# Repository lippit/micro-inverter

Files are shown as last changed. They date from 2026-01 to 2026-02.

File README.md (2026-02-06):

# An open-source - community built micro-inverter

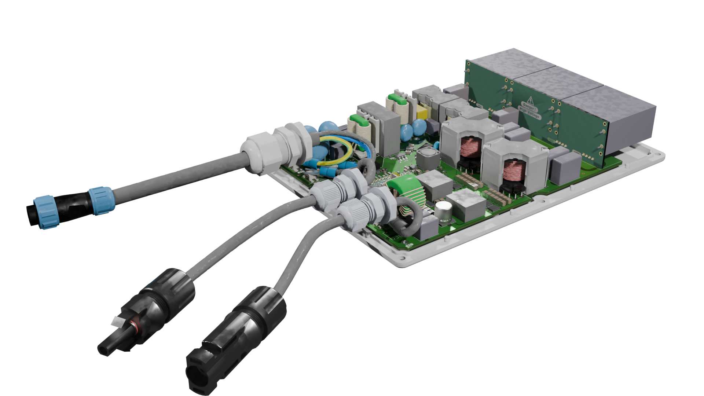
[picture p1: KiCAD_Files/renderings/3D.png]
3D view


## Manifesto 

The project goal are : 

- Having the first open source PV micro-inverter
- Finally a design easy to repair that is no longer a black box
- Redeem your data sovereignty, you will no longer depend on a proprietary cloud to follow your solar production and consumption. 

## Open, for everyone, forever

- This project is propulsed by its community. 
- The collective work generated is meant to remain open. 
- Design files are made with open source software - Namely kiCAD.
- Mechanical interfaces and components are modeled using FreeCAD.
- Simulation files use ngSpice.

In that sense, the owntech foundation aims at protecting this technical common.

## Specifications
This section is inspired from OpenMi

Comparison of micro-inverters with rated output power between 350VA and 400VA:

| Model | HM-350 | HM-400 | IQ7A |EVT300  |TSOL-M800  |
|:---|:---:|:---:|:---:|:---:|:---:|
| Manufacturer | Hoymiles | Hoymiles | Enphase | Envertech | TSUN |
| Number of solar panels | 1 | 1 | 1 | 1 | 2 |
| Recommended input power (W) | 280-470+ | 320-540+ | 295-460 | 180-420+ |2 $\cdot$ 280-440|
| $V_{MPPT,min}$ (V) | 33 | 34 | 38 (18) | 24 | 33 |
| $V_{MPPT,max}$ (V) | 48 | 48 | 43 (58) | 45 | 48 |
| Start-up voltage (V) | 22 | 22 | 22 | - | - |
| Operating volage range (V) | 16-60 | 16-60 | 16-58 | 18-54 | 16-60 |
| Maximum input current (A) | 11.5 | 12 | 12 | 12 | 11.5 |
| Maximum input short circuit current (A)| 15 | 15 | 20 | 15 | 15 |
| Rated output power (VA) | 350 | 400 | 349 | 300 | 600 |
| Peak efficiency (%) | 96.7 | 96.7 | 97.7 | 95.4 | 96.7 |
| CEC weighted efficiency (%) | 96.5 | 96.5 | 97.0 | 95.0 | 96.5 |

### uVerter Target specifications

| Category | Requirement | Notes |
|---|---:|---|
| Grid | 220 V AC to 250V AC / 50 to 60 Hz | Hardware not compatible with 110V grids |
| Grid compliance | Grid-code compliant | Exact certification scope depends on country / standard |
| Rated apparent power | 450 VA | Software-limited power cap supported |
| Input DC operating range | 16 V – 58 V | PV module operating window |
| Recommended PV input power | 350 W – 550 W | Depends on module and thermal conditions |
| Efficiency | > 95% | Target at nominal conditions |
| Power factor | ≈ 1 | Near-unity PF at rated power |
| THD | < 5% | Total harmonic distortion at rated conditions |
| Isolation | Galvanic isolation | Electrical isolation between PV and grid |
| Operating temperature | -40 °C to +60 °C | Derating may apply |
| Repairability | No invasive potting | Designed to be serviceable / inspectable |
| Connectivity | Wi-Fi | Local-first monitoring (no proprietary cloud required) |

## Renderings

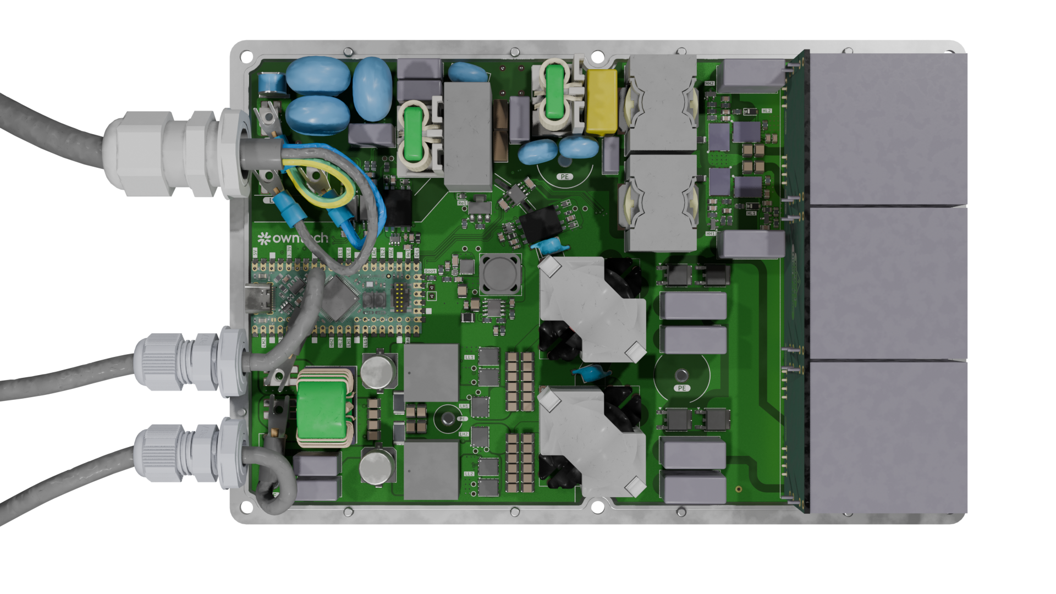
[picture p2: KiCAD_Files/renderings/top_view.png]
Top view


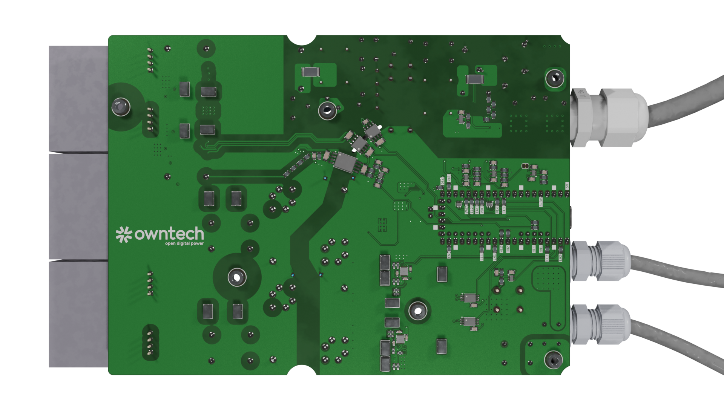
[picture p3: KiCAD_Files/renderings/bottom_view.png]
Bottom view


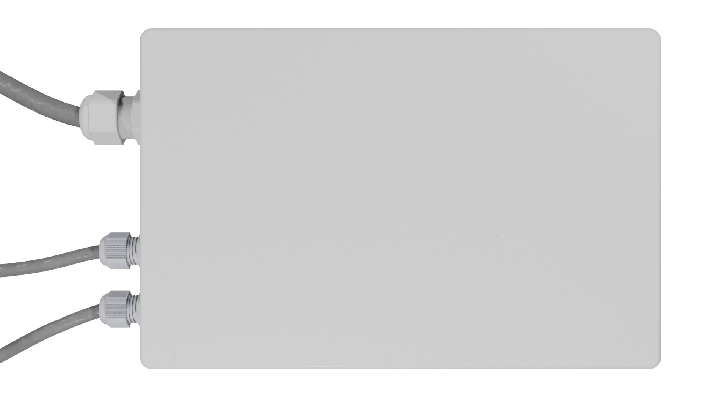
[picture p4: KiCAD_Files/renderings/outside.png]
Outside view


## Control overview

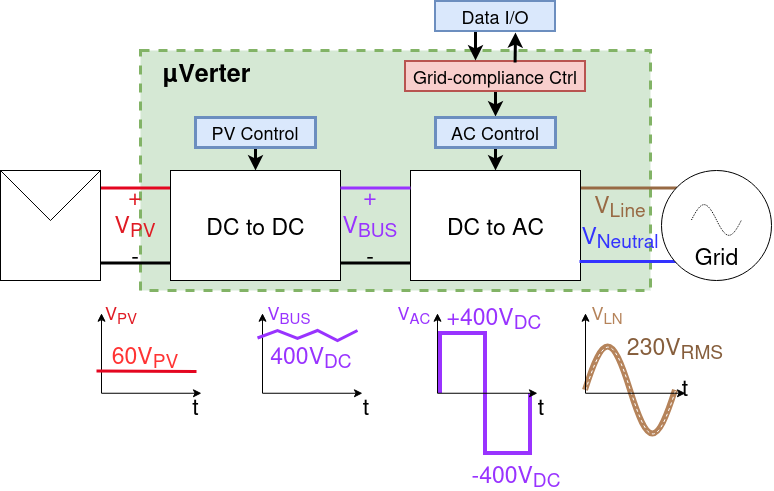
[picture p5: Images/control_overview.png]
Control overview


The control overview shows the uVerter as two coordinated stages: a PV-controlled DC/DC front end that regulates the panel operating point and raises the DC bus, followed by an AC control stage that shapes a grid-compliant AC output. Measurements and commands flow through Data I/O and the grid-compliance controller so the inverter can synchronize to line/neutral, limit harmonics, and maintain safe operation while power flows from the PV input to the grid.

## Firmware overview

The `firmware/src/main.cpp` file is the entry point for the uVerter firmware: it configures the sensors and power stages, sets up the real-time and background tasks, and runs the state machine plus control loops that drive the boost and inverter legs based on measurements and synchronization status.

- Real-time control runs in `loop_critical_task()` at 100 µs to read sensors, enforce protections, regulate the boost stage, compute duty cycles, and update grid-sync variables.
- Supervisory logic runs in `loop_application_task()` to manage modes (idle/startup/power/error), handle transitions, and expose telemetry through the user data API.

### Compiling

Micro-inverter uses [PlatformIO](https://platformio.org/) as it's build and dependency management system.

#### From the command line

1. Create and activate a Python virtual environment.

        python3 -m venv .owntech-venv
        source .owntech-venv/bin/activate

2. Install PlatformIO.

        pip3 install platformio

3. Compile the code. Dependencies (including Zephyr and Owntech libraries) are downloaded automatically.

        cd micro-inverter/firmware/
        pio run

#### In Visual Studio Code

1. Install the "PlatformIO IDE" extension
2. Open the `firmware` directory via PlatformIO's home screen (**not** with VSCode's File -> Open)
3. Press the "Build" button in the PlatformIO toolbar (found on the bottom left)

## Contribute 

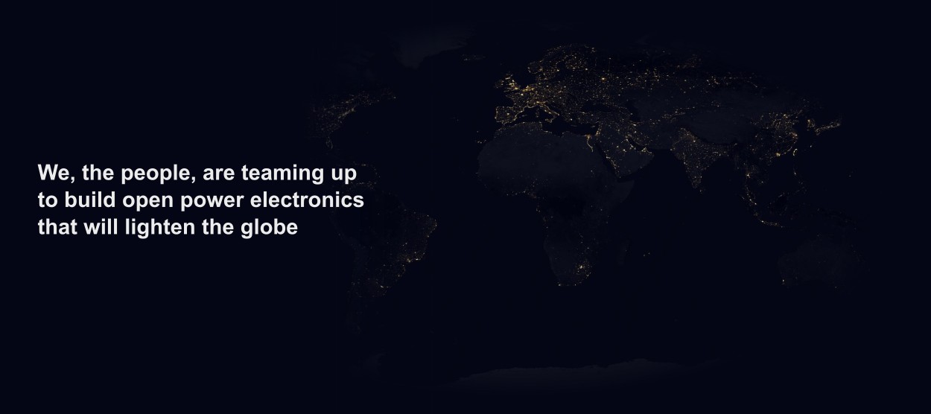
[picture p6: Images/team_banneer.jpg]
Team banneer


### Spread the word

- ⭐ Star this repository  

- Share the project with PV / power electronics / open-hardware communities  

- Mention it in meetups, forums, maker spaces, or your local energy co-op  

### Give feedback and report issues

Help us improve by opening GitHub issues:

- Bug reports (schematic/PCB mistakes, BOM mismatches, mechanical interferences)  

- Documentation gaps (unclear steps, missing diagrams, confusing naming)  

- Feature requests  

### Choose a contribution path

Start with Contribute.md — a living list of work items the community can pick up.  
Whether you’re a student looking for a thesis topic, an engineer wanting to review a safety-critical design, or a maker growing skills in hardware and firmware: you’re welcome here.  

Bring what you have: time, curiosity, test equipment, careful eyes, lived experience installing or repairing PV gear.  
Let’s build an inverter that isn’t a black box — and keep it open, for everyone, forever.  

## Safety first  

### Disclaimer
This project is shared as-is, without any warranty of any kind, and without any guarantee of compliance with safety, EMC, or grid-connection regulations.
By building, modifying, or using this design, you accept full responsibility for verification, testing, certification (if applicable), and safe operation.

Do not connect a prototype to the public grid.
Grid connection must only happen after appropriate validation, protections, and (where required) third-party certification.

### Mind the risks  
Building a micro-inverter is an advanced DIY project. It combines high energy, high voltage, fast switching, and grid interaction — a mix that can injure, start fires, or damage property

Key hazards include:

- Electric shock and electrocution
Internal stages can reach hundreds of volts. Multiple nets are high voltage. Some capacitors can stay charged after power-off. Treat the system as live until proven discharged and measured.

- Fire and thermal runaway
Faults can turn traces, connectors, inductors, or semiconductors into heaters in seconds. Thermal issues can escalate quickly.

### A community note
We want this project to be open — not reckless. If you spot a safety issue (creepage/clearance, insulation, thermal margins, protection logic, connector ratings, etc.), please report it.
Safety improvements are contributions that protect everyone.

## Standards and directives

### Relevant EU directives for CE

- Directive 2001/95/EC: General Product Safety
- Directive 2014/30/EU: Electromagnetic Compatibility (EMC)
- Directive 2014/35/EU: Low Voltage (LVD)
- Directive 2014/53/EU: Radio Equipment (RED)
- Directive 2011/65/EU: Restriction of the use of certain Hazardous Substances (RoHS)

### Low Voltage Directive (LVD)

**EN IEC 62109-1:2010**
Safety of power converters for use in photovoltaic power systems - Part 1: General requirements

**EN IEC 62109-2:2011**
Safety of power converters for use in photovoltaic power systems - Part 2: Particular requirements for inverters

### Electromagnetic Compatibility (EMC)

**EN 62920:2017+A11+A1:2021**
Photovoltaic power generating systems - EMC requirements and test methods for power conversion equipment

**ETSI EN 301 489-1**
ElectroMagnetic Compatibility (EMC) standard for radio equipment and services; Part 1: Common technical requirements

**ETSI EN 301 489-17**
ElectroMagnetic Compatibility (EMC) standard for radio equipment and services; Part 17: Specific conditions for Broadband Data Transmission Systems

### Radio Equipment Directive (RED)

**ETSI EN 300 328 V2.2.2**
Wideband transmission systems; Data transmission equipment operating in the 2,4 GHz band; Harmonised Standard for access to radio spectrum

### Grid Regulations

As grid regulations are country specific, please refer to Grid regulations

## Licence 

This project is licenced under **CERN-OHL-V2-S** open source hardware licence. Licence file can be found under `License/cern-ohl-v2-s`.

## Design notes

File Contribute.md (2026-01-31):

Team Banneer

# Contribute

This project is a technical common: open, repairable, auditable, and built by its community.  
Whether you bring careful eyes, lab time, code, documentation, or field experience — you’re welcome.

If you’re unsure where to start: open an issue, introduce yourself, and tell us what you’d like to work on.

---

## How to get involved

### 1) Pick a contribution path
Choose a topic below (Hardware / Firmware / Dataware). Each topic contains hands-on work items you can adopt.

### 2) Coordinate in public
Before starting large changes, please:
- Check existing issues / discussions
- Open a new issue describing your plan (scope + expected outcome)
- Share progress early (screenshots, measurements, logs)

This keeps effort aligned and avoids duplicated work.

### 3) Make a pull request
A good PR is small, reviewable, and documented:
- One clear purpose per PR
- Explain *what* changed and *why*
- Include screenshots for PCB/mechanical changes
- Include measurements / plots / logs when relevant
- Link the issue it addresses (e.g. `Fixes #123`)

---

## Contribution topics

## Hardware (KiCad / FreeCAD / lab work)

- Create a thermal model for the uVerter. 
- Explore how we could extend DCDC stage to more solar panels using interleaving.
- Explore how to create an optimized casing for the uVerter.

---

## Firmware (control, protection, bring-up)

- Add a hard real-time protection layer in `loop_critical_task()` that can force “cease to energize” (e.g., `shield.power.stop(ALL)` plus gate/relay disable) within grid-code limits, independent of control flow.
- Improve ride-through vs anti-islanding by tuning synchronization logic in `loop_critical_task()` (e.g., `is_net_synchronized`, `sync_counter`, `desync_counter`) and refining the `STARTUPMODE`/`POWERMODE` transitions in `loop_application_task()`.
- Implement deterministic grid-code behaviors with explicit timing using the state machine in `loop_application_task()` and setpoint/duty shaping in `loop_critical_task()` (e.g., `rate_limiter()` for ramps and `mode_asked` for reconnection delays).

---

## Dataware (local-first monitoring, APIs, UX)

- Wire an ESP32 on top of the spin board and implement a minimalistic WIFI monitoring using thingset protocol.

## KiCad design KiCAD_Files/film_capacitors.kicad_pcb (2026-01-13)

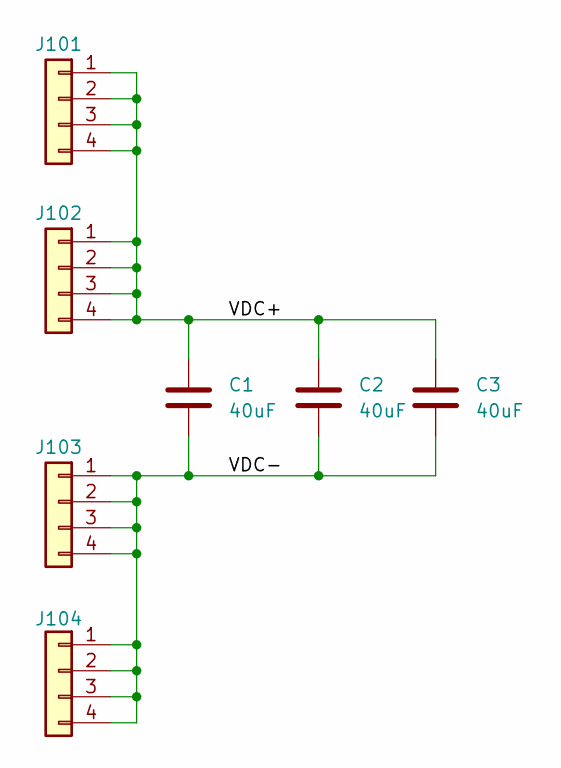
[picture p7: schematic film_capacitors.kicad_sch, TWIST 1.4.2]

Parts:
C1, C2, C3: 40uF; 40uF_film; LCSC C52120702
J101, J102, J103, J104: Conn_01x04; PinHeader_1x04_P2.54mm_Horizontal; LCSC C492412

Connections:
/VDC+: C1.1, C2.1, C3.1, J101.1, J101.2, J101.3, J101.4, J102.1, J102.2, J102.3, J102.4
/VDC-: C1.2, C2.2, C3.2, J103.1, J103.2, J103.3, J103.4, J104.1, J104.2, J104.3, J104.4

Board: 2 copper layers, 18 parts (6 on the bottom side), 2 nets, no tracks yet.

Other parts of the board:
kibuzzard-696561C2: G***; kibuzzard-696561C2
kibuzzard-6965612A: G***; kibuzzard-6965612A
kibuzzard-6965618E, kibuzzard-6965618E#2: G***; kibuzzard-6965618E
kibuzzard-69656115: G***; kibuzzard-69656115
kibuzzard-69656160, kibuzzard-69656160#2: G***; kibuzzard-69656160
kibuzzard-69656174, kibuzzard-69656174#2: G***; kibuzzard-69656174
kibuzzard-69656181, kibuzzard-69656181#2: G***; kibuzzard-69656181

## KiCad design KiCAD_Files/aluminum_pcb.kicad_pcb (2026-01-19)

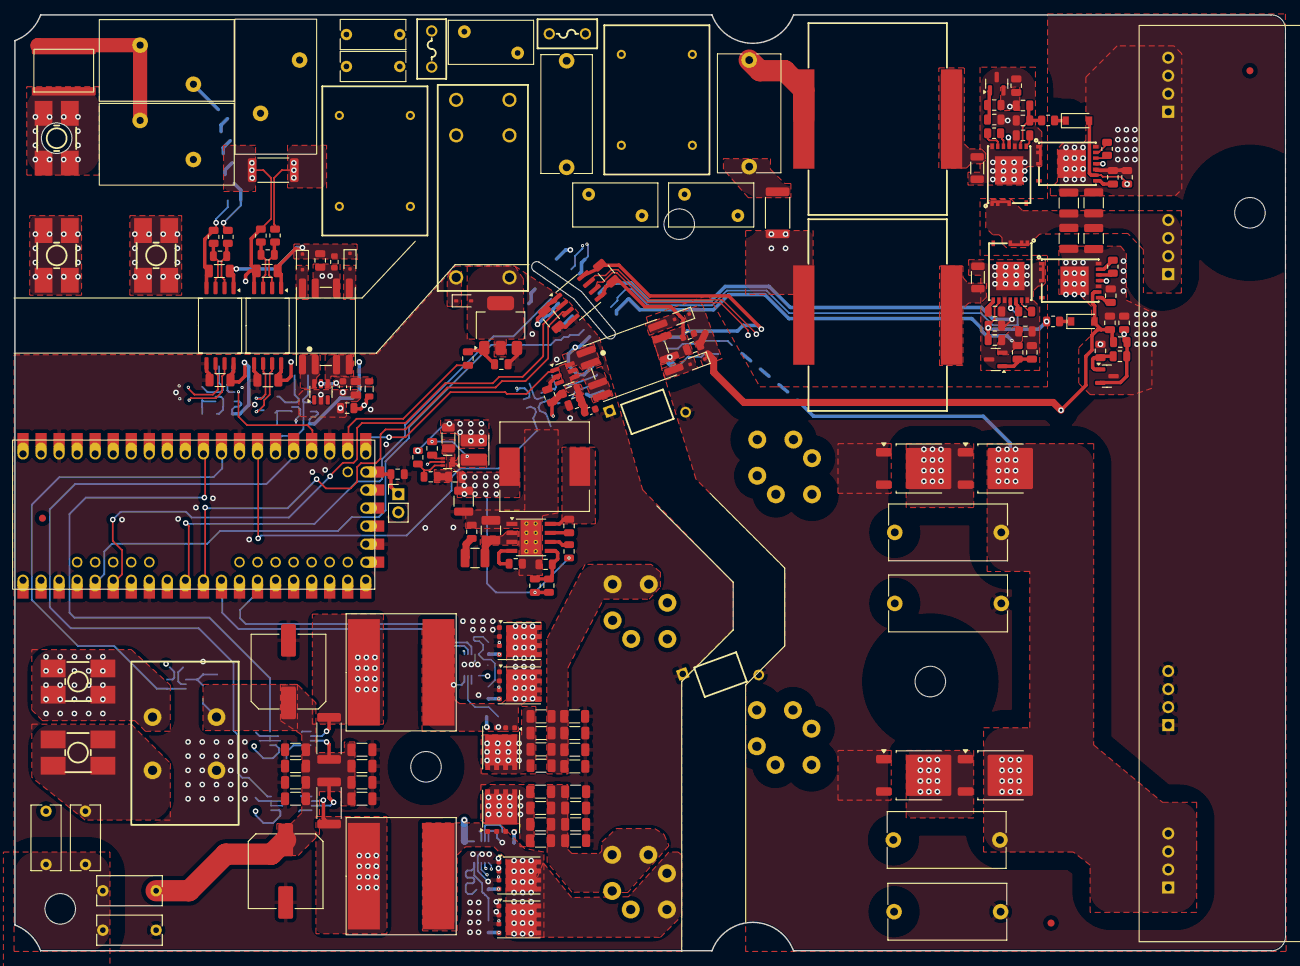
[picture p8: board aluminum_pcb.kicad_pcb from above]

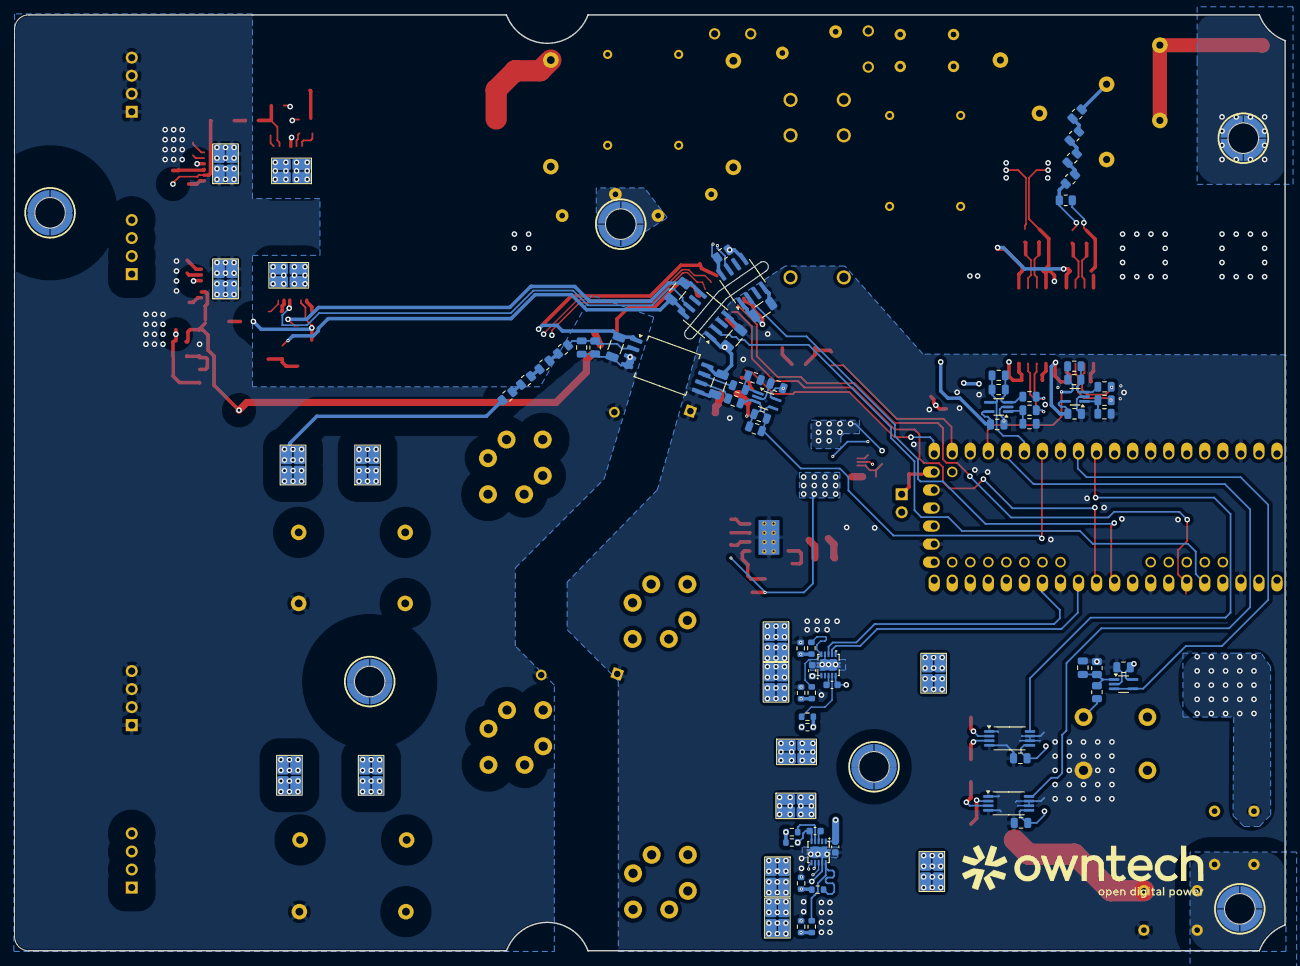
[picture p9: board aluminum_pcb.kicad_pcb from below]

Board: 4 copper layers, 178.9 x 131.8 mm, 277 parts (91 on the bottom side), 144 nets.

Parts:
C1, C3, C12, C13, C14, C15: C_Small; C_0805_2012Metric
C5, C10, C11, C54, C116, C117: 2.2nF; C_Rect_L9.0mm_W4.0mm_P7.50mm_MKT
C6: 120µF; film_capacitors
C7: 680nF; C_Rect_L16.5mm_W8.7mm_P15.00mm_MKT
C8, C9, C40, C53: 470nF; C_0603_1608Metric
C16, C17, C114, C115: 1nF; C_1210_3225Metric
C18, C25, C34, C103, C110: 10µF; C_1206_3216Metric
C19, C20, C21, C23, C24, C26, C29, C30, C32, C35, C36, C37, C104, C105, C106, C107, C108, C109: C; C_1206_3216Metric
C22, C27, C33, C38: 680nF; C_Rect_L16.5mm_W8mm_P15.00mm_MKT
C28, C39, C44, C405, C505, C702, C703, C707, C804, C807, C808, C809: 100nF; C_0805_2012Metric
C31: 10 µF; C_1206_3216Metric
C42, C47, C402, C403, C502, C503, C801, C802, C803, C805, C806: 100nF; C_1206_3216Metric
C43, C46, C404, C501, C504: 20pF; C_0805_2012Metric
C101, C102: 4.7uF; C_0805_2012Metric
C111: 47uF; C_Elec_10x10.2
C112: 47uH; C_Elec_10x10.2
C113: ?nF; C_Rect_L16.5mm_W7.0mm_P15.00mm_MKT
C118, C119: 1nF; CAP-TH_L6.3-W4.4-P10.00-D0.6-S3.8
C401: 100pF; C_0805_2012Metric
C701: 1nF; C_0805_2012Metric
C704: 22uF; C_1210_3225Metric
C705: 33pF; C_0805_2012Metric
C706, C709, C710, C711, C712, C715, C716: 10uF; C_0805_2012Metric
C708: 47uF; C_1206_3216Metric
C713, C714: 100nF; C_0603_1608Metric
C717: 470nF; C_0805_2012Metric
C718: 4.7uF; C_1210_3225Metric
D1, D2, D3, D4: D_Schottky; Diode_TO-252-2
D5: 40V - BAT165E6327F; D_SOD-323
D101, D102: D; D_SOD-123
D701, D702, D703, D704: PMEG3010; D_SOD-323F
F1, F101: 2.5A; FUSE-TH_L8.4-W4.1-P5.08-D0.6
FB1, FB2: 300@100MHz; L_1206_3216Metric
FID1, FID2, FID3: Fiducial; Fiducial_1mm_Mask2mm
FL1, FL2: 5mH; FILTER-TH_XRSQ1515-5MH-V-1013
FL3: 1mH; IND-TH_4P-L23.0-W15.0-P7.50-D1.0-S9.0
GD1: 2R600B-8S; SMD_GDT
H1, H2, H3, H4, H5, H6: M3x3.5; SMD_BD5.6-D4.1
HS3, HS4, HS5, HS9, HS10, HS11, HS12, HS101, HS104, HS105, HS106, HS107, HS108, HS109, HS110, HS111: 5x3mm pad 3mm high; BTC-533-ZN01
J1, J2, J3, J5, J8: Conn_01x01; SMD-4_TS34056055-0440
JP901: Jumper_2_Open; PinHeader_1x02_P2.54mm_Vertical
K1: HF140FF/012-2HSWTF; RELAY-TH_HF140FF-024-2HSWT
L1, L3: 330uH; IND-SMD_L27.0-W19.5-LS23.5_60B104C
L5, L6: 33uH; SRP1510CA-330M
L701: 68uH - 70mR; L_12x12mm_H6mm
L702: 4.7uH - 80mR; L_Cenker_CKCS4020
L703, L704: 10uH; L_0805_2012Metric
L705: 10uH; L_1210_3225Metric
Logo1: owntech34mmneg
Logo101: owntech_mini10
N101: Die cast enclosure BS11 / G124 /1550G; Die Cast Casing 1550G
Q1, Q2, Q3, Q4: CID12N65D; DFN-10_L8.0-W6.0_CID12N65D
Q5, Q6, Q7, Q8, Q9, Q10: CJAC90SN12; DFN-8-1EP_5x6_P1.27mm
Q11: ZXMN7A11GTA; SOT-223
R1, R2, R4, R5: R_Small; R_0805_2012Metric
R3: 4.7R; R_2512_6332Metric
R6, R9: 10k; R_0603_1608Metric
R7, R10: 5mR; R_2512_6332Metric
R8, R32, R33, R101, R109: 20k; R_0603_1608Metric
R12: 56R; C_0805_2012Metric
R13, R801, R802, R805, R806, R808, R809: 10k; C_0805_2012Metric
R14, R15, R16, R17, R401, R402, R403, R404, R501, R502, R503, R504, R901: 27k; R_0805_2012Metric
R102, R103: 3.3R; R_0805_2012Metric
R104, R105, R106, R107, R108: 20; R_0603_1608Metric
R701: 110k; R_0805_2012Metric
R702, R706: 10k; R_0805_2012Metric
R703: 65k; R_0805_2012Metric
R704: 100k; R_0805_2012Metric
R705: 56k; R_0805_2012Metric
R707, R708: 4.7k; R_0603_1608Metric
R803, R804: 1k; C_0805_2012Metric
R807: 470; C_0805_2012Metric
RV1, RV2, RV3: 14D621; RV_Disc_D15.5mm_W11mm_P7.5mm
RV101, RV102, RV103: TMOV14RP275; RV_Disc_D12mm_W6.2mm_P7.5mm
Rv14: 3mR; R_2512_6332Metric
Rv15, Rv16, Rv506, Rv507: 12R; R_0805_2012Metric
Rv401, Rv402, Rv403, Rv404, Rv701: 1M; R_0805_2012Metric
Rv405, Rv505: 1k; R_0805_2012Metric
Rv501, Rv502, Rv503, Rv504: 333k; R_0805_2012Metric
Rv702: 16K; R_0805_2012Metric
T1, T2: Transformer_1P_1S; RM12
TR701: VPT87DDF01B; VPT87BB-01B
TR702: VPT87DFB01B; VPT87BB-01B
U1: INA240A1PW; TSSOP-8_4.4x3mm_P0.65mm
U2: INA240A1PWR; TSSOP-8_4.4x3mm_P0.65mm
U3, U4: UCC27282DRC; VSON-10_L3.0-W3.0-P0.50-TL-EP
U5, U501: AMC1301DWR; SOIC-8_7.5x5.85mm_P1.27mm
U8, U402, U502, U701: MCP6486UT-E/LT; SOT-353_SC-70-5_Handsoldering
U401: AMC1311BDWVR; SOIC-8_7.5x5.85mm_P1.27mm
U702: TPS562202; SOT-563
U703, U704: VPS8701B; SOT-23-6
U707: LMR38020SDDAR; Texas_HSOP-8-1EP_3.9x4.9mm_P1.27mm_ThermalVias
U801, U802, U803: ISO7720FDR; SOIC-8_3.9x4.9mm_P1.27mm
U804: TL431DBZ; SOT-23
U805, U806: TL431; SOT-23
U901: OwnTech_SPIN; OwnTech_SPINTHT_1

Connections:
+3.3V_{DGND}: JP901.2 (B), U901.36 (+3.3V)
+5V_{ACsense}: C47.2, C502.2, C716.1, D703.1 (K), D704.1 (K), R708.1, U5.1 (VDD1), U501.1 (VDD1)
+5V_{DGND}: C28.1, C39.1, C42.2, C44.1, C403.2, C405.1, C503.2, C505.1, C702.1, C708.1, C801.2, C803.2, C805.2, L702.2, R705.1, U1.5 (V+), U2.5 (V+), U5.8 (VDD2), U8.5 (V+), U401.8 (VDD2), U402.5 (V+), U501.8 (VDD2), U502.5 (V+), U701.5 (V+), U801.1 (VCC1), U802.1 (VCC1), U803.1 (VCC1), U901.40 (+VIN)
+5V_{HV}: C402.2, C806.2, C809.1, R807.2, R808.1, U401.1 (VDD1), U803.8 (VCC2), U806.2 (K)
+5V_{SN1}: C802.2, C807.1, R801.1, R803.2, U801.8 (VCC2), U804.2 (K)
+5V_{SN2}: C804.2, C808.1, R804.2, R805.1, U802.8 (VCC2), U805.2 (K)
+12V_{DGND}: C9.1, C53.1, C704.1, C705.1, C706.1, C709.1, C710.1, D5.1 (K), K1.8, L701.2, L703.1, L704.1, R701.1, R704.2, U3.1 (VDD), U4.1 (VDD), U702.1 (VIN), U702.5 (EN)
+12V_{HV}: C13.1, C15.1, C715.1, D101.2 (A), D102.2 (A), D701.1 (K), D702.1 (K), Q3.6 (VCC), Q4.6 (VCC), R707.1, R807.1
+12V_{SN1}: C101.1, Q2.6 (VCC), R102.1, R803.1
+12V_{SN2}: C102.1, Q1.6 (VCC), R103.1, R804.1
/Feeder/DIS_{HV}: U703.1 (EN), U901.21 (PB9)
/Feeder/Neut_{REF}: C47.1, C502.1, C716.2, FL2.3, R708.2, Rv14.2, Rv16.1, Rv505.2, Rv507.1, TR702.6 (SB), TR702.7 (SA), U5.4 (GND1), U501.4 (GND1)
/Feeder/V_{ILow}: C717.1, L705.1
/Microcontroller/BOOT0: JP901.1 (A), R901.1, U901.58 (PB8)
/Microcontroller/EN_{I}: U3.6 (EN), U4.6 (EN), U901.19 (PC12)
/Microcontroller/I_{AC}: C43.2, R17.2, U8.4, U901.26 (PC2)
/Microcontroller/I_{ILow1}: U1.8, U901.30 (PA1)
/Microcontroller/I_{ILow2}: U2.8, U901.25 (PC1)
/Microcontroller/PWM_{IHigh1}: U3.7 (HI), U901.12 (PA8)
/Microcontroller/PWM_{IHigh2}: U4.7 (HI), U901.2 (PB12)
/Microcontroller/PWM_{IIHigh1}: U801.2 (INA), U901.5 (PB14)
/Microcontroller/PWM_{IIHigh2}: U802.2 (INA), U901.10 (PC8)
/Microcontroller/PWM_{IILow1}: U803.2 (INA), U901.6 (PB15)
/Microcontroller/PWM_{IILow2}: U803.3 (INB), U901.11 (PC9)
/Microcontroller/PWM_{ILow1}: U3.8 (LI), U901.14 (PA9)
/Microcontroller/PWM_{ILow2}: U4.8 (LI), U901.4 (PB13)
/Microcontroller/Relay: R12.1, U901.22 (PC13)
/Microcontroller/V_{AC}: C504.2, R504.2, U502.4, U901.24 (PC0)
/Microcontroller/V_{DCBus}: C404.2, R404.2, U402.4, U901.27 (PC3)
/Microcontroller/V_{ILow}: U701.3 (-), U701.4, U901.29 (PA0)
/Power/AC Current sense/In+: J2.1, RV2.2, RV3.2, Rv14.1, Rv15.1
/Power/Grid Voltage sense/In+: FL2.2, J1.1, RV1.1, RV2.1, Rv501.1
/Power/HO1: R105.2, U3.4 (HO)
/Power/HO2: R107.2, U4.4 (HO)
/Power/HV_{BUS}: C6.1, C16.1, C17.1, C22.1, C33.1, C114.1, C115.1, D1.1 (K), D3.1 (K), HS5.1, HS101.1, Q1.1 (D), Q1.4, Q2.1 (D), Q2.4, Rv401.1
/Power/LO1: R104.2, R108.2, U3.10 (LO)
/Power/LO2: R106.2, R109.2, U4.10 (LO)
/Power/LSW1: C40.2, HS107.1, HS108.1, L5.2, Q5.1 (S), Q6.3 (D), Q7.3 (D), R6.1, T1.8 (AA), T1.9 (AA), U3.5 (HS)
/Power/LSW2: C8.2, HS105.1, HS106.1, L6.2, Q8.1 (S), Q9.3 (D), Q10.3 (D), R9.1, T2.8 (AA), T2.9 (AA), U4.5 (HS)
/Power/LSW3: C29.2, C30.2, C31.2, C32.2, C34.1, C35.1, C36.1, C37.1, T2.11 (AB), T2.12 (AB)
/Power/LSW4: C18.2, C19.2, C20.2, C21.2, C23.1, C24.1, C25.1, C26.1, T1.11 (AB), T1.12 (AB)
/Power/PWM_{IIHigh1}: Q2.8 (PWM), U801.7 (OUTA)
/Power/PWM_{IIHigh2}: Q1.8 (PWM), U802.7 (OUTA)
/Power/PWM_{IILow1}: Q3.8 (PWM), U803.7 (OUTA)
/Power/PWM_{IILow2}: Q4.8 (PWM), U803.6 (OUTB)
/Power/Rect1: D1.2 (A), D2.1 (K), HS11.1, T1.2 (SB)
/Power/Rect2: D3.2 (A), D4.1 (K), HS12.1, T2.2 (SB)
/Power/ThPad_{IND1}: HS110.1, L5.1, R7.1, U1.2 (+)
/Power/ThPad_{IND2}: HS111.1, L6.1, R10.1, U2.2 (+)
/Power/V_{IHigh1}: C18.1, C19.1, C20.1, C21.1, HS104.1, Q5.3 (D)
/Power/V_{IHigh2}: C29.1, C30.1, C31.1, C32.1, HS109.1, Q8.3 (D)
/Power/V_{ILow}: C103.2, C104.2, C105.2, C106.2, C107.2, C108.2, C109.2, C110.2, C111.1, C112.1, C116.2, FL3.2, R7.2, R10.2, Rv701.1, U1.3 (-), U2.3 (-)
/SN1: C3.2, C101.2, C802.1, C807.2, FB2.1, HS3.1, Q2.7 (SGND), Q2.11 (PGND), Q2.12 (S), Q3.1 (D), Q3.4, R802.2, U801.5 (GND2), U804.3 (A)
/SN2: C1.2, C102.2, C804.1, C808.2, FB1.1, HS4.1, Q1.7 (SGND), Q1.11 (PGND), Q1.12 (S), Q4.1 (D), Q4.4, R806.2, U802.5 (GND2), U805.3 (A)
DGND: C9.2, C23.2, C24.2, C25.2, C26.2, C28.2, C34.2, C35.2, C36.2, C37.2, C39.2, C42.1, C44.2, C53.2, C103.1, C104.1, C105.1, C106.1, C107.1, C108.1, C109.1, C110.1, C111.2, C112.2, C117.2, C118.1, C119.1, C403.1, C405.2, C503.1, C505.2, C701.2, C702.2, C704.2, C706.2, C708.2, C709.2, C710.2, C711.2, C712.2, C713.2, C714.2, C717.2, C718.2, C801.1, C803.1, C805.1, FL3.3, Q6.1 (S), Q7.1 (S), Q9.1 (S), Q10.1 (S), Q11.3 (S), R8.1, R13.2, R16.2, R32.1, R33.1, R101.1, R403.2, R503.2, R702.2, R703.2, R706.2, R901.2, Rv702.2, U1.1 (GND), U1.4 (GND), U1.6 (REF2), U1.7 (REF1), U2.1 (GND), U2.4 (GND), U2.6 (REF2), U2.7 (REF1), U3.9 (VSS), U3.11 (ThermalPad), U4.9 (VSS), U4.11 (ThermalPad), U5.5 (GND2), U8.2 (V-), U401.5 (GND2), U402.2 (V-), U501.5 (GND2), U502.2 (V-), U701.2 (V-), U702.3 (GND), U703.2 (GND), U704.2 (GND), U707.1 (GND), U707.9 (GND), U801.4 (GND1), U802.4 (GND1), U803.4 (GND1), U901.3 (GND), U901.8 (GND), U901.13 (GND), U901.18 (GND), U901.23 (GND), U901.28 (GND), U901.33 (GND), U901.38 (GND), U901.54 (GND), U901.57 (GND)
Earth_Protective: C5.2, C10.1, C11.1, C54.1, C116.1, C117.1, GD1.1, H1.1, H2.1, H3.1, H4.1, H5.1, H6.1, J3.1, RV102.2, RV103.2
GND_{HV}: C6.2, C12.2, C13.2, C14.2, C15.2, C16.2, C17.2, C27.2, C38.2, C114.2, C115.2, C118.2, C119.2, C401.2, C402.1, C715.2, C806.1, C809.2, D2.2 (A), D4.2 (A), HS9.1, HS10.1, Q3.7 (SGND), Q3.11 (PGND), Q3.12 (S), Q4.7 (SGND), Q4.11 (PGND), Q4.12 (S), R707.2, R809.2, Rv405.2, TR701.6 (SB), TR701.7 (SA), U401.3 (SHTDN), U401.4 (GND1), U803.5 (GND2), U806.3 (A)
unnamed: C5.1, FL2.1, K1.3
unnamed: C7.1, FL1.1, L1.2
unnamed: C7.2, R3.1
unnamed: C10.2, FL2.4, K1.5
unnamed: C113.1, F1.2, K1.4, RV102.1
unnamed: C113.2, F101.2, K1.6, RV103.1
unnamed: D5.2 (A), K1.1, Q11.2 (D), Q11.4 (D)
unnamed: D101.1 (K), R102.2
unnamed: D102.1 (K), R103.2
unnamed: D701.2 (A), TR701.8 (SB)
unnamed: D702.2 (A), TR701.5 (SA)
unnamed: D703.2 (A), TR702.8 (SB)
unnamed: D704.2 (A), TR702.5 (SA)
unnamed: F1.1, FL1.2, RV101.1
unnamed: F101.1, FL1.3, RV101.2
unnamed: FB1.2, L1.1
unnamed: FB2.2, L3.1
unnamed: FL1.4, L3.2, R3.2
unnamed: GD1.3, RV1.2, RV3.1
unnamed: C11.2, FL3.1, J5.1
unnamed: C54.2, FL3.4, J8.1
unnamed: Q1.9 (OUT+), R1.1
unnamed: Q1.10 (OUT-), R1.2
unnamed: C1.1, Q1.5 (VDD)
unnamed: Q2.9 (OUT+), R2.1
unnamed: Q2.10 (OUT-), R2.2
unnamed: C3.1, Q2.5 (VDD)
unnamed: Q3.9 (OUT+), R4.1
unnamed: Q3.10 (OUT-), R4.2
unnamed: C12.1, Q3.5 (VDD)
unnamed: Q4.9 (OUT+), R5.1
unnamed: Q4.10 (OUT-), R5.2
unnamed: C14.1, Q4.5 (VDD)
unnamed: Q5.2 (G), R6.2, R105.1
unnamed: Q6.2 (G), R32.2, R104.1
unnamed: Q7.2 (G), R8.2, R108.1
unnamed: Q8.2 (G), R9.2, R107.1
unnamed: Q9.2 (G), R33.2, R106.1
unnamed: Q10.2 (G), R101.2, R109.1
unnamed: Q11.1 (G), R12.2, R13.1
unnamed: Rv401.2, Rv402.1
unnamed: Rv402.2, Rv403.1
unnamed: Rv403.2, Rv404.1
unnamed: Rv501.2, Rv502.1
unnamed: Rv502.2, Rv503.1
unnamed: Rv503.2, Rv504.1
unnamed: Rv504.2, Rv505.1, Rv506.1
unnamed: C22.2, C27.1, T1.5 (SA)
unnamed: C33.2, C38.1, T2.5 (SA)
unnamed: C40.1, U3.3 (HB)
unnamed: C8.1, U4.3 (HB)
unnamed: C46.1, Rv16.2, U5.3 (VINN)
unnamed: C46.2, Rv15.2, U5.2 (VINP)
unnamed: R15.1, U5.6 (VOUTN)
unnamed: R14.1, U5.7 (VOUTP)
unnamed: R14.2, R16.1, U8.1 (+)
unnamed: C43.1, R15.2, R17.1, U8.3 (-)
unnamed: C401.1, Rv404.2, Rv405.1, U401.2 (VIN)
unnamed: R402.1, U401.6 (VOUTN)
unnamed: R401.1, U401.7 (VOUTP)
unnamed: R401.2, R403.1, U402.1 (+)
unnamed: C404.1, R402.2, R404.1, U402.3 (-)
unnamed: C501.1, Rv507.2, U501.3 (VINN)
unnamed: C501.2, Rv506.2, U501.2 (VINP)
unnamed: R502.1, U501.6 (VOUTN)
unnamed: R501.1, U501.7 (VOUTP)
unnamed: R501.2, R503.1, U502.1 (+)
unnamed: C504.1, R502.2, R504.1, U502.3 (-)
unnamed: C701.1, Rv701.2, Rv702.1, U701.1 (+)
unnamed: C707.2, L702.1, U702.2 (SW)
unnamed: C707.1, U702.4 (VBST)
unnamed: R705.2, R706.1, U702.6 (VFB)
unnamed: TR701.1 (AA), TR701.2 (AA), U703.6 (VD1)
unnamed: TR701.3 (AB), TR701.4 (AB), U703.4 (VD2)
unnamed: C711.1, C713.1, L703.2, U703.5 (VIN)
unnamed: TR702.1 (AA), TR702.2 (AA), U704.6 (VD1)
unnamed: TR702.3 (AB), TR702.4 (AB), U704.4 (VD2)
unnamed: C712.1, C714.1, L704.2, U704.5 (VIN)
unnamed: C703.1, U707.7 (BOOT)
unnamed: C718.1, L705.2, U707.2 (EN), U707.3 (VIN)
unnamed: C705.2, R701.2, R702.1, U707.5 (FB)
unnamed: R704.1, U707.6 (PG)
unnamed: R703.1, U707.4 (RT/Sync)
unnamed: C703.2, L701.1, U707.8 (SW)
unnamed: R801.2, R802.1, U804.1 (REF)
unnamed: R805.2, R806.1, U805.1 (REF)
unnamed: R808.2, R809.1, U806.1 (REF)

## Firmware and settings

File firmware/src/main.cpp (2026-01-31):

/*
 *
 * Copyright (c) 2021-2024 LAAS-CNRS
 *
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
 * SPDX-License-Identifier: LGPL-2.1
 */

/**
 * @brief  This file is the main entry point of the
 *         OwnTech Power API. Please check the OwnTech
 *         documentation for detailed information on
 *         how to use Power API: https://docs.owntech.org/
 *
 * @author Clément Foucher <clement.foucher@laas.fr>
 * @author Luiz Villa <luiz.villa@laas.fr>
 */

//-------------- OWNTECH APIs ---------------------------------
#include "TaskAPI.h"
#include "ShieldAPI.h"
#include "SpinAPI.h"
#include "auxiliary.h"

// Control library
#include "trigo.h"
#include "filters.h"
#include "ScopeMimicry.h"
#include "control_factory.h"
#include "singlePhaseInverter.h"
#include "sogi.h"
#include "user_data_api.h"
#include <zephyr/console/console.h>
#include <zephyr/sys/printk.h>


#define DUTY_MIN 0.1F
#define DUTY_MAX 0.9F
#define UDC_STARTUP 0.0F

//-------------- SETUP FUNCTIONS DECLARATION ------------------
/* Setups the hardware and software of the system */
void setup_routine();

//-------------- LOOP FUNCTIONS DECLARATION -------------------
// Code to be executed in the background task
void loop_application_task();
// Code to be executed in real time in the critical task
void loop_critical_task();

//-------------- USER VARIABLES DECLARATIONS ------------------
// [us] period of the control task
static const uint32_t control_task_period = 100;
// [bool] state of the PWM (ctrl task)
static bool pwm_enable = false;

// Measurement variables
float32_t Vlow_value;     // [V]
float32_t Vac_value;      // [V]
float32_t Ilow1_value;    // [A]
float32_t Ilow2_value;    // [A]
float32_t Vdc_bus;        // [V]
float32_t Iac_value;      // [A]
float32_t Vdc_bus_filt;   // [V]
float32_t meas_data;      // holds the measurement for validation

// [A] Current offset found experimentally 21/10/2025
static float32_t I1_current_offset = 0.25F;
static float32_t I2_current_offset = 0.25F; // [A]

float32_t Vgrid_meas; // [V]
float32_t VN_meas;    // [V]
float32_t Igrid_meas; // [A]

static singlePhaseInverter inverter;

static dqo_t power;


static dqo_t Vdq;        // Vdq measure (in)
static dqo_t Vdq_output; // Inverter output
dqo_t Vdq_ref;
dqo_t Vdq_ref_max;
dqo_t Vdq_ref_min;
static float32_t Valpha_in_out;

static dqo_t Idq;
dqo_t Idq_ref;
dqo_t Idq_ref_max;
dqo_t Idq_ref_min;
static dqo_t Idq_ref_delta;




static float32_t Id_ref_delta = 0.0;
static float32_t Iq_ref_delta = 0.0;


static float32_t Vd_ref_max = 20.0F;
static float32_t Vd_ref_min = 0.0F;


static clarke_t Vab;
static clarke_t Vab_output;
static clarke_t Iab;

static float32_t Vond;
static float32_t R_load = 10;

static float32_t Ialpha, Ibeta;
static bool is_net_synchronized;
static float32_t omega;

inverter_mode local_mode = FOLLOWING;

// Duty-cycle control
static float32_t delta_duty_cycle;   // [no unit]
static float32_t duty_cycle_1;       // [no unit]
static float32_t duty_cycle_2;       // [no unit]
static float32_t duty_cycle_offset;  // [no unit]
static float32_t boost_duty_cycle = 0.05F;
static uint16_t boost_pos_dt = 100;
static uint16_t boost_neg_dt = 100;
float32_t boost_voltage_reference = 33.0F;
bool boost_pwm_enable = false;
bool inverter_on = false;

static float32_t Udc = 63.0F;        // dc voltage supply assumed [V]
static const float f0 = 50.0F;       // fundamental frequency [Hz]
static const float32_t w0 = 2.0F * PI * f0;   // pulsation [rad/s]
static const float32_t sync_power_tolerance = 0.01F * w0;

// Sinewave settings
static float32_t Vgrid_ref; // [V]
static float32_t Vgrid_amplitude_ref = 20.0F; // [V]
static float32_t Vgrid_amplitude = 20.0F; // [V]
static float angle = 0.0F; // [rad]
static float theta = 0.0F; // [rad]

//------------- PR RESONANT -----------------------------------
float32_t Ts = control_task_period * 1.0e-6F;

// kp is small due to the pure delay system (ref Viking)
static float32_t kp = 0.001F;
static float32_t Ti = 0.001F / 3000; // Ti is Kp/Ki
float32_t Td = 0.0F;
float32_t N = 1.0F;
float32_t upper_bound = Udc;
float32_t lower_bound = -Udc;

static Pid pi_current_d = controlLibFactory.pid(Ts, kp, Ti, Td, N,
                                                lower_bound, upper_bound);
static Pid pi_current_q = controlLibFactory.pid(Ts, kp, Ti, Td, N,
                                                lower_bound, upper_bound);

static Pid pi_voltage_d = controlLibFactory.pid(Ts, 0.01, 0.003, Td, N,
                                                lower_bound, upper_bound);
static Pid pi_voltage_q = controlLibFactory.pid(Ts, 0.01, 0.003, Td, N,
                                                lower_bound, upper_bound);

static float32_t boost_kp = 0.000215F;
static float32_t boost_Ti = 7.5175e-5F;
static float32_t boost_Td = 0.0F;
static float32_t boost_N = 0.0F;
static float32_t boost_upper_bound = 1.0F;
static float32_t boost_lower_bound = 0.0F;
static Pid boost_pid = controlLibFactory.pid(Ts, boost_kp, boost_Ti,
                                             boost_Td, boost_N,
                                             boost_lower_bound,
                                             boost_upper_bound);
Sogi sogi_i;
Sogi sogi_v;


// Comes from "filters.h"
LowPassFirstOrderFilter vHighFilter(Ts, 0.1F);
LowPassFirstOrderFilter VqFilter(Ts, 1.0F);
static uint32_t critical_task_counter;
static uint32_t decimation = 1;
static uint32_t sync_counter = 0;
static uint32_t desync_counter = 0;
static uint32_t power_counter = 0;
static float32_t desync_counter_scope;
static bool sync_start_flag = false;
static float32_t Vq_filtered;

// Scope records data during the critical task
// (library included via platformio.ini)
ScopeMimicry scope(1024, 19);
bool is_downloading;
bool trigger = false;
//---------------------------------------------------------------

static uint8_t mode = IDLEMODE;
uint8_t mode_asked = IDLEMODE;
static float32_t spying_mode = 0;
static const float32_t MAX_CURRENT = 8.0F;

//-------------- SETUP FUNCTIONS ------------------------------

/**
 * This is the setup routine.
 * It is used to call functions that will initialize your hardware and tasks.
 * In this example, we setup the version of the spin board and a 
 * background task. The critical task is defined but not started.
 * NOTE: It is important to follow the steps and initialize the hardware first 
 * and the tasks second. 
 */
void setup_routine()
{
    // Setup the hardware first
    enableUSolarVerterSensors();

    // Boost control on low legs (parallel boost)
    shield.power.initBoost(LEG1_LOW);
    shield.power.initBoost(LEG2_LOW);

    scope.connectChannel(Ilow1_value, "Ilow1_value");
    scope.connectChannel(Iac_value, "Iac_value");
    scope.connectChannel(Vgrid_meas, "Vgrid");
    scope.connectChannel(Vdc_bus, "Vdc_bus");
    scope.connectChannel(duty_cycle_1, "duty_cycle_1");
    scope.connectChannel(duty_cycle_2, "duty_cycle_2");
    scope.connectChannel(Idq.d, "Id");
    scope.connectChannel(Idq.q, "Iq");
    scope.connectChannel(Idq_ref.d, "Id_ref");
    scope.connectChannel(Iab.alpha, "Ialpha");
    scope.connectChannel(Iab.beta, "Ibeta");
    scope.connectChannel(Vdq.q, "Vq_in");
    scope.connectChannel(Vdq.d, "Vd_in");
    scope.connectChannel(Vdq_output.q, "Vq_out");
    scope.connectChannel(Vdq_output.d, "Vd_out");
    scope.connectChannel(Vab.alpha, "Valpha");
    scope.connectChannel(Vab.beta, "Vbeta");
    scope.connectChannel(Valpha_in_out, "Valpha(out-in)");
    scope.connectChannel(Vab_output.alpha, "ValphaOut");
    scope.connectChannel(Vab_output.beta, "VbetaOut");
    scope.set_delay(0.5F);
    scope.set_trigger(a_trigger);
    scope.start();

    // PR initialization
    inverter.init(local_mode, Udc, Vgrid_amplitude_ref, w0, Ts);

    sogi_v.init(500.0, Ts);
    sogi_i.init(500.0, Ts);

    Idq_ref.d = 0.0;
    Idq_ref.q = 0.0;
    Vdq_ref.d = 0.0;
    Vdq_ref.q = 0.0;

    Idq_ref_max.d = 8.0;
    Idq_ref_max.q = 1.0;
    Idq_ref_min.d = -0.1;
    Idq_ref_min.q = -0.1;

    Vdq_ref_max.d = 30.0;
    Vdq_ref_max.q = 30.0;
    Vdq_ref_min.d = -0.1;
    Vdq_ref_min.q = -0.1;



    Idq_ref_delta.d = 0.0;
    Idq_ref_delta.q = 0.0;



    pi_current_d.reset();
    pi_current_q.reset();
    pi_voltage_d.reset();
    pi_voltage_q.reset();
    is_net_synchronized = false;

    /* Buck voltage mode */
    shield.power.initBuck(LEG1_HIGH);
    shield.power.initBuck(LEG2_HIGH);

    // Then declare tasks
    uint32_t app_task_number = task.createBackground(loop_application_task);
    task.createCritical(loop_critical_task, control_task_period);

    // Finally, start tasks
    task.startBackground(app_task_number);
    task.startCritical();
}

//-------------- LOOP FUNCTIONS -------------------------------

/**
 * This is the code loop of the background task
 * It is executed second as defined by it suspend task in its last line.
 * You can use it to execute slow code such as state-machines.
 */
void loop_application_task()
{
/* --- STATE MACHINE --------------------------------------------------------*/
// mode is the STATE variable
// in each state we compute the transitions
switch (mode) {
        case IDLEMODE:

            if (mode_asked == POWERMODE) {
                mode = POWERMODE;
            }
            spin.led.turnOn();
        break;
        case STARTUPMODE:
            if (!inverter_on) {
                mode = POWERMODE;
            }
            if (local_mode == FORMING && delta_duty_cycle > 0.49F)
            {
                mode = POWERMODE;
            } 
            else if (local_mode == FOLLOWING && is_net_synchronized) 
            {
                mode = POWERMODE;
                if (is_net_synchronized) spin.led.toggle();
            }

        break;
        case POWERMODE:
            if (mode_asked == IDLEMODE) {
                mode = IDLEMODE;
            }
            if (inverter_on) {
                if (local_mode == FORMING) {
                    if (Vdc_bus_filt >= UDC_STARTUP) {
                        mode = STARTUPMODE;
                    } 
                } else {
                    if (Vgrid_meas >= 10 && Vdc_bus_filt >= UDC_STARTUP) {
                        mode = STARTUPMODE;
                    }
                }
                if (is_net_synchronized) spin.led.toggle();
            }
        break;
        case ERRORMODE:
        break;
    }
    if (mode_asked == IDLEMODE) {
        mode = IDLEMODE; // global return to idle possible
    }
/* --- END OF STATE MACHINE -------------------------------------------------*/

    if (mode == IDLEMODE)
    {
        if (is_downloading) {
            dump_scope_datas(scope);
            is_downloading = false;
        }
    }

    user_live.mode = mode;
    user_live.omega = omega;
    user_live.vgrid_amp_ref = Vgrid_amplitude_ref;
    user_live.power_d = power.d;
    user_live.power_q = power.q;
    user_live.idq_ref_d = Idq_ref.d;
    user_live.idq_ref_delta_d = Idq_ref_delta.d;
    user_live.vdq_ref_d = Vdq_ref.d;
    user_live.vdq_ref_q = Vdq_ref.q;
    task.suspendBackgroundMs(100);
}

/**
 * This is the code loop of the critical task
 * It is executed every 100 micro-seconds defined in the setup_software
 * function. You can use it to execute an ultra-fast code with the highest
 * priority which cannot be interruped.
 * It is from it that you will control your power flow.
 */
void loop_critical_task()
{
    critical_task_counter++;

    // Retrieve measurements
    meas_data = shield.sensors.getLatestValue(ILow1);
    if (meas_data != NO_VALUE) Ilow1_value = meas_data - I1_current_offset;

    meas_data = shield.sensors.getLatestValue(VLow);
    if (meas_data != NO_VALUE) Vlow_value = meas_data;

    meas_data = shield.sensors.getLatestValue(VAC);
    if (meas_data != NO_VALUE) Vac_value = meas_data;

    meas_data = shield.sensors.getLatestValue(ILow2);
    if (meas_data != NO_VALUE) Ilow2_value = meas_data - I2_current_offset;

    meas_data = shield.sensors.getLatestValue(VDCBus);
    if (meas_data != NO_VALUE) Vdc_bus = meas_data;

    meas_data = shield.sensors.getLatestValue(IAC);
    if (meas_data != NO_VALUE) Iac_value = meas_data;

    Vdc_bus_filt = vHighFilter.calculateWithReturn(Vdc_bus);

    Vgrid_meas = Vlow_value - Vac_value;
    VN_meas = (Vlow_value + Vac_value) / 2;
    Igrid_meas = Ilow1_value;

    user_meas.v_low = Vlow_value;
    user_meas.v_ac = Vac_value;
    user_meas.v_dc_bus = Vdc_bus;
    user_meas.i_low1 = Ilow1_value;
    user_meas.i_low2 = Ilow2_value;
    user_meas.i_ac = Iac_value;
    user_meas.v_dc_bus_filt = Vdc_bus_filt;
    user_meas.v_grid = Vgrid_meas;
    user_meas.v_n = VN_meas;
    user_meas.i_grid = Igrid_meas;

    // Overcurrent protection
    if (Ilow1_value > MAX_CURRENT
        || Ilow1_value < -MAX_CURRENT
        || Ilow2_value > MAX_CURRENT
        || Ilow2_value < -MAX_CURRENT)
    {
        mode = ERRORMODE;
    }


    if (mode == IDLEMODE || mode == ERRORMODE)
    {
        // FIRST WE STOP THE PWM
        if (pwm_enable == true)
        {
            shield.power.stop(ALL);
            spin.led.turnOff();
            pwm_enable = false;
        }
        if (boost_pwm_enable == true)
        {
            shield.power.stop(LEG1_LOW);
            shield.power.stop(LEG2_LOW);
            boost_pwm_enable = false;
        }
    }

    // Boost stage enabled in startup and power modes
    if (mode == STARTUPMODE || mode == POWERMODE) {
        boost_duty_cycle = boost_pid.calculateWithReturn(
            boost_voltage_reference,
            Vdc_bus_filt
        );
        shield.power.setDeadTime(LEG1_LOW, boost_pos_dt, boost_neg_dt);
        shield.power.setDeadTime(LEG2_LOW, boost_pos_dt, boost_neg_dt);
        shield.power.setDutyCycle(LEG1_LOW, boost_duty_cycle);
        shield.power.setDutyCycle(LEG2_LOW, boost_duty_cycle);
        if (!boost_pwm_enable)
        {
            shield.power.start(LEG1_LOW);
            shield.power.start(LEG2_LOW);
            boost_pwm_enable = true;
        }
    }

    // Stop inverter legs when not enabled
    if (!inverter_on) {
        if (pwm_enable == true)
        {
            shield.power.stop(LEG1_HIGH);
            shield.power.stop(LEG2_HIGH);
            pwm_enable = false;
        }
    }

    // Startup ramp and synchronization logic
    // Ramp up the common voltage to Udc/2
    if (mode == STARTUPMODE && inverter_on) {

        if (local_mode == FORMING) {

            // Ramp of 50/s
            delta_duty_cycle = rate_limiter(0.5F,
                                            delta_duty_cycle,
                                            50.0F);
            if (delta_duty_cycle > 0.5F) {
                delta_duty_cycle = 0.5F;
            }
            shield.power.setDutyCycle(LEG2_HIGH, 1 - delta_duty_cycle);
            shield.power.setDutyCycle(LEG1_HIGH, delta_duty_cycle);
            // WE START THE PWM
            if (!pwm_enable)
            {
                shield.power.start(ALL);
                pwm_enable = true;
            }

        } else {
            inverter.calculateDuty(Vgrid_meas, Igrid_meas);
            Vdq = inverter.getVdq();
            omega = inverter.getw();

            if (omega < w0 + sync_power_tolerance &&
                omega > w0 - sync_power_tolerance)
            {
                sync_counter++;
                if (sync_counter > 2000) {
                    is_net_synchronized = true;
                    sync_counter = 0;                                    
                }
            } else {
                sync_counter = 0;
                is_net_synchronized = false;                
            }

        }
    }

    // Closed-loop control in power mode
    if (mode == POWERMODE && inverter_on)
    {
        delta_duty_cycle = inverter.calculateDuty(Vgrid_meas, Igrid_meas);
        omega = inverter.getw();

        is_net_synchronized = omega <= w0 + sync_power_tolerance &&
                              omega >= w0 - sync_power_tolerance;

        if (!is_net_synchronized)
        {
            desync_counter++;
            desync_counter_scope = (float32_t)desync_counter;
            if (desync_counter > 200) {
                desync_counter = 0;
                sync_counter = 0;
                mode_asked = IDLEMODE;
                mode = IDLEMODE;
                printk("System no longer synchronized \n");
            }                
        }

        inverter.setVBus(Vdc_bus_filt);

        if (local_mode == FORMING) {
            inverter.setVdqRef(Vdq_ref);
        } else {
            inverter.setIdqRef(Idq_ref);
        }

        if (!pwm_enable)
        {        
            duty_cycle_offset = VN_meas/Vdc_bus_filt;        
        } 
        else
        {
            if (duty_cycle_offset < 0.5F) {
                // Ramp of 0.1 duty / 100 ms
                duty_cycle_offset = rate_limiter(0.5F,
                                                 duty_cycle_offset,
                                                 1.0F);
                
            } else {
                duty_cycle_offset = 0.5F;
            }

        }


        duty_cycle_1 = delta_duty_cycle + duty_cycle_offset;
        duty_cycle_2 = -delta_duty_cycle + duty_cycle_offset;
        
        if (local_mode == FOLLOWING && !pwm_enable)
        {
            power_counter++;
            if (power_counter > 2000) {
                shield.power.start(ALL);
                pwm_enable = true;
            }
        }



        shield.power.setDutyCycle(LEG1_HIGH, duty_cycle_1);
        shield.power.setDutyCycle(LEG2_HIGH, duty_cycle_2);

    }

    /* Retrieve multiple data for debugging */
    theta = inverter.getTheta();
    Vdq = inverter.getVdq();
    Vq_filtered = VqFilter.calculateWithReturn(Vdq.q);
    Vdq_output = inverter.getVdqOut();
    Vab = inverter.getVab();
    Vab_output = inverter.getVabOutput();
    Iab = inverter.getIab();
    Idq = inverter.getIdq();
    Idq_ref_delta = inverter.getIdqRefDelta();
    omega = inverter.getw();
    Valpha_in_out = Vab_output.alpha - Vab.alpha; 

    user_inv_dbg.theta = theta;
    user_inv_dbg.vab_alpha = Vab.alpha;
    user_inv_dbg.vab_beta = Vab.beta;
    user_inv_dbg.vab_out_alpha = Vab_output.alpha;
    user_inv_dbg.vab_out_beta = Vab_output.beta;
    user_inv_dbg.iab_alpha = Iab.alpha;
    user_inv_dbg.iab_beta = Iab.beta;
    user_inv_dbg.vdq_d = Vdq.d;
    user_inv_dbg.vdq_q = Vdq.q;
    user_inv_dbg.vdq_out_d = Vdq_output.d;
    user_inv_dbg.vdq_out_q = Vdq_output.q;
    user_inv_dbg.idq_d = Idq.d;
    user_inv_dbg.idq_q = Idq.q;

    user_boost_dbg.duty_leg1 = boost_duty_cycle;
    user_boost_dbg.duty_leg2 = boost_duty_cycle;
    user_boost_dbg.dt_rise_ns = boost_pos_dt;
    user_boost_dbg.dt_fall_ns = boost_neg_dt;


    if (critical_task_counter % decimation == 0) {
        spying_mode = (float32_t) mode;
        scope.acquire();
    }
}

/**
 * This is the main function of this example
 * This function is generic and does not need editing.
 */
int main(void)
{
    setup_routine();

    return 0;
}

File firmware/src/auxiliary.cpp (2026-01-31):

#include "auxiliary.h"

#include "TaskAPI.h"
#include "ShieldAPI.h"
#include "SpinAPI.h"
#include "singlePhaseInverter.h"
#include "user_data_api.h"
#include <zephyr/sys/printk.h>

extern ScopeMimicry scope;
extern bool is_downloading;
extern bool trigger;
extern bool inverter_on;
extern inverter_mode local_mode;
extern dqo_t Vdq_ref_max;
extern dqo_t Vdq_ref_min;
extern dqo_t Vdq_ref;
extern dqo_t Idq_ref_max;
extern dqo_t Idq_ref_min;
extern dqo_t Idq_ref;
extern float32_t Ts;
extern uint8_t mode_asked;

bool a_trigger()
{
    return trigger;
}

void dump_scope_datas(ScopeMimicry &scope)
{
    scope.reset_dump();
    printk("begin record\n");
    while (scope.get_dump_state() != finished) {
        printk("%s", scope.dump_datas());
        task.suspendBackgroundUs(100);
    }
    printk("end record\n");
}

void app_apply_command(void)
{
    switch (user_cmd.mode_request) {
        case IDLEMODE:
            mode_asked = IDLEMODE;
            break;
        case POWERMODE:
            if (!is_downloading) {
                scope.start();
            }
            mode_asked = POWERMODE;
            break;
        default:
            break;
    }

    inverter_on = user_cmd.inverter_on;

    if (local_mode == FORMING) {
        float32_t vd = user_cmd.vd_ref;
        if (vd > Vdq_ref_max.d) {
            vd = Vdq_ref_max.d;
        }
        if (vd < Vdq_ref_min.d) {
            vd = Vdq_ref_min.d;
        }
        Vdq_ref.d = vd;
        user_cmd.vd_ref = vd;
    } else {
        float32_t id = user_cmd.id_ref;
        if (id > Idq_ref_max.d) {
            id = Idq_ref_max.d;
        }
        if (id < Idq_ref_min.d) {
            id = Idq_ref_min.d;
        }
        Idq_ref.d = id;
        user_cmd.id_ref = id;
    }

    if (user_cmd.scope_dump) {
        is_downloading = true;
        trigger = false;
        user_cmd.scope_dump = false;
    }
    if (user_cmd.scope_trigger) {
        trigger = true;
        user_cmd.scope_trigger = false;
    }
}

float32_t saturate(const float32_t x, float32_t min, float32_t max)
{
    if (x > max) {
        return max;
    }
    if (x < min) {
        return min;
    }
    return x;
}

float32_t sign(float32_t x, float32_t tol)
{
    if (x > tol) {
        return 1.0F;
    }
    if (x < -tol) {
        return -1.0F;
    }
    return 0.0F;
}

float32_t rate_limiter(const float32_t ref,
                       float32_t value,
                       const float32_t rate)
{
    value += Ts * rate * sign(ref - value);
    return value;
}

void enableUSolarVerterSensors()
{
    spin.data.configureTriggerSource(ADC_1, TRIG_PWM);
    spin.data.configureTriggerSource(ADC_2, TRIG_PWM);
    spin.data.configureTriggerSource(ADC_3, TRIG_SOFTWARE);
    spin.data.configureTriggerSource(ADC_4, TRIG_SOFTWARE);
    spin.data.configureTriggerSource(ADC_5, TRIG_SOFTWARE);

    spin.data.configureDiscontinuousMode(ADC_1, 1);
    spin.data.configureDiscontinuousMode(ADC_2, 1);

    shield.sensors.enableSensor(ILow1, ADC_1);
    shield.sensors.enableSensor(VLow, ADC_1);
    shield.sensors.enableSensor(VDCBus, ADC_1);

    shield.sensors.enableSensor(ILow2, ADC_2);
    shield.sensors.enableSensor(VAC, ADC_2);
    shield.sensors.enableSensor(IAC, ADC_2);
}

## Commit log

2025-07-16 Changed the architecture from DAB to full-bridge. Added low side feeder.
    [Driver_High.kicad_sch, Feeder.kicad_sch, feeder.kicad_sch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]
2026-01-13 Schematic close to completion.
    [AC_voltage_sense.kicad_sch, DC_HV_voltage_sense.kicad_sch, Driver_High.kicad_sch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]
2026-01-16 First routing pass complete.
    [AC_voltage_sense.kicad_sch, DC_HV_voltage_sense.kicad_sch, HV_driver.kicad_sch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]
2026-01-17 Added missing tracks for sensors and relay. Fixed many routing issues.
    [Microcontroller.kicad_sch, aluminum_pcb.kicad_pcb, aluminum_pcb.kicad_sch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]
2026-01-19 Added DRC rules according to IEC60664 and IPC2221.
    [AC_voltage_sense.kicad_sch, DC_HV_voltage_sense.kicad_sch, Microcontroller.kicad_sch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]
2026-01-19 Added PE keepouts. Adding thermal vias. DRC passing.
    [aluminum_pcb.kicad_pcb, power.kicad_sch]
2026-01-19 Added HF X2 caps, Improved low side Y2 placement. Improved Silkscreen.
    [power.kicad_sch]
2026-01-23 Added passive references. Added ESD protection for MCU pins.
    [AC_voltage_sense.kicad_sch, DC_HV_voltage_sense.kicad_sch, Microcontroller.kicad_sch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]
2026-01-23 Added TL431 for AC measurement 5V regulation. Added more film capacitance. Increased size of 100V ceramic caps to 1210.
    [AC_voltage_sense.kicad_sch, DC_HV_voltage_sense.kicad_sch, Microcontroller.kicad_sch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]
2026-01-27 V0.9 as ordered 23/01/26. Improved silkscreen, added 1nF on enable pin signals.
    [feeder.kicad_sch, power.kicad_sch]
2026-01-27 Tidy up repo structure.
    [Driver.kicad_sch, Driver_High.kicad_sch, Feeder.kicad_sch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]
2026-01-27 Suppressing non relevant footprints and 3D files.
2026-01-27 Tidied up the schematic. Added the pdf version for V0.9.
    [AC_voltage_sense.kicad_sch, DC_HV_voltage_sense.kicad_sch, Microcontroller.kicad_sch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]
2026-01-29 Added mechanical assets - cabling, cable glands, MC4 and AC connectors.
2026-01-30 Adding ngspice simulations for EMC. Adding schematic pdf.
    [Common_mode.kicad_sch, Differential_mode.kicad_sch, Inverter_spectrum.kicad_sch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]
2026-02-03 Modified the differential inductor filter footprints slightly. Solves #2.
    [feeder.kicad_sch, power.kicad_sch]
2026-02-03 Added LSW3 and LSW4 netclass (Fix #3). Tidied up courtyard DRC for testpoints.
    [feeder.kicad_sch, power.kicad_sch]

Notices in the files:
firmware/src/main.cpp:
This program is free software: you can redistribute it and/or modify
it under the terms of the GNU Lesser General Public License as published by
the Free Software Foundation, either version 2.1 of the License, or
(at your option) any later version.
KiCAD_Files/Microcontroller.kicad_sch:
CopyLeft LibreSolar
